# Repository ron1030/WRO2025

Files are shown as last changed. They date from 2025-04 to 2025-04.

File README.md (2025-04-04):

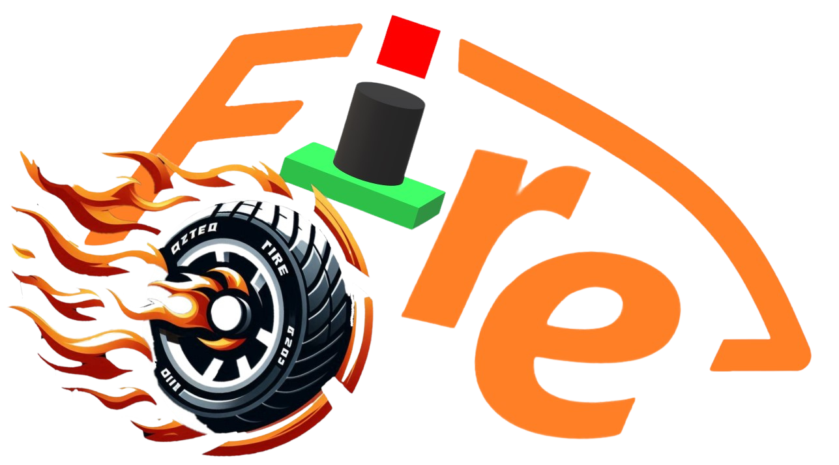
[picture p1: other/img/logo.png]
logo
 

- This is the official GitHub repository for the WRO TAIWAN team "__Fire On All Cylinders.__" All code, documentation, and files are located here.
- The design inspiration for both the hardware and software of this self-driving car came from last year’s model created by our sister team (Shinan-Fire-On-All-Cylinders) and drew upon the strengths of the world championship-winning model from last year. Based on this, we made improvements by upgrading the main controller from the "Raspberry Pi 4B" to the "Nvidia Jetson Nano" to enhance performance and introduce innovative design elements, making the vehicle more competitive.
- Here you can find the links to the technical report content and setup instructions, organized separately for learners and judges, for easy access during either learning or assessment. 
- In this technical document, the directory will be established based on the scoring criteria, and the directory headings will be hyperlinked for easy access for judges or learners to navigate to the key content of the technical document, facilitating quick assessment.
- **Special Reminder:** Due to internet speed factors, images may not display properly. If this occurs, please try refreshing the webpage to resolve the issue.
    #### [For Learners](learners_contents.md)
## Rubric for Judging Engineering Documentation 
- ###  ${{\color{red} Hardware Overview }} $ 
  #### 1. Mobility Management
    * [1-1 Vehicle 2D/3D Models in CAD ](models/Vehicle_2D_3D/README.md)
    * [1-2 Vehicle Chassis Design ](schemes/Vehicle_Chassis_Design/README.md)
    * [1-3 Motor Selection ](schemes/Motor/README.md)

  #### 2. Power and Sense Management
    - __2-1 Vehicle Design__
      - [2-1-1 BOM Parts List ](schemes/Parts_List/README.md)
      - [2-1-2 Circuit Design ](models/Circuit_Design/README.md)
      - [2-1-3 Hardware Fool-Proof Design ](schemes/Fool-Proof-Design/README.md) 
      - [2-1-4 Assembly Instructions & Wiring Diagrams ](schemes/Assembly_Instructions/README.md)    
      
    - __2-2 Power Management__
      - [2-2-1 Battery choice for self-driving cars ](schemes/Battery/README.md)  
      - [2-2-2 Power Supply System ](schemes/Power_Supply_System/README.md) 
   
    - __2-3 Controller Selection__
      - [2-3-1 Main Controller Comparison ](schemes/Main_Controller_Choosing/README.md)
      - [2-3-2 Motor & Sensor Intermediate I/O Controller Comparison ](schemes/Motor_Sensor_Controller_Choosing/README.md)
    - __2-4 Sense Management__
      - [2-4-1 Ultrasonic rangefinder ](schemes/HC-SR04/README.md)
      - [2-4-2 Gyroscope orientation sensor ](schemes/BNO055/README.md)
      - [2-4-3 Camera Selection ](schemes/Camera/README.md)
  
- ### ${{\color{red} Software Overview }} $ 
  #### 3. Obstacle Management
    - [3-1 Software Platform Construction ](src/System_Platform_Software/README.md)
    - [3-2 OpenCV Introduction ](src/OpenCV/README.md)
    - __3-3 Image Recognition Processing and Steering__
      - [3-3-1 Image Recognition Processing ](src/Image_Recognition_Processing/README.md)  
      - [3-3-2 Steering Control ](src/Steering_Control/README.md) 
      - [3-3-3 Automatically record the HSV values of the field ](src/Automatically_record_HSV/README.md)
    - __3-4 Programming__
      - [3-4-1 Open Challenge Code Overview ](src/Programming/Open_Challenge/README.md)
      - [3-4-2 Obstacle Challenge Code Overview ](src/Programming/Obstacle_Challenge/README.md)
      - [3-4-3 Distinctive Pseudo Code ](src/Distinctive_Pseudo_Code/README.md)
      - [3-4-4 Parking Instruction ](src/parking/README.md)
    - __3-5 Remote Connection__
      - [3-5-1 NoMachine Introduction ](other/NoMachine/README.md)
- ### ${{\color{red} Other}} $
  #### 4. Pictures – Team and Vehicle
    - [4-1 Team Members Introduction ](t-photos/README.md)
    - [4-2 Vehicle Photos ](v-photos/README.md)  
  #### 5. Performance Videos
    - [5-1 Open Challenge ](video/Open_Challenge/video.md)
    - [5-2 Obstacle Challenge ](video/Obstacle_Challenge/video.md)
    - [5-3 Self-Driving Car Design Process Video](video/Design_Process_Video/video.md)
  #### 6. GitHub Utilization
    - [6-1 GitHub Edit(VScode Edit/GIT) ](src/GitHub_Edit/README.md)
    - [6-2 GitHub Web Editing Languages ](src/GitHub_Languages/README.md)  
  #### 7. Engineering Factor  
    - [7-1 Work Diary](other/work_diary/README.md)
- ### ${{\color{red} CompetitionSchedule}} $  
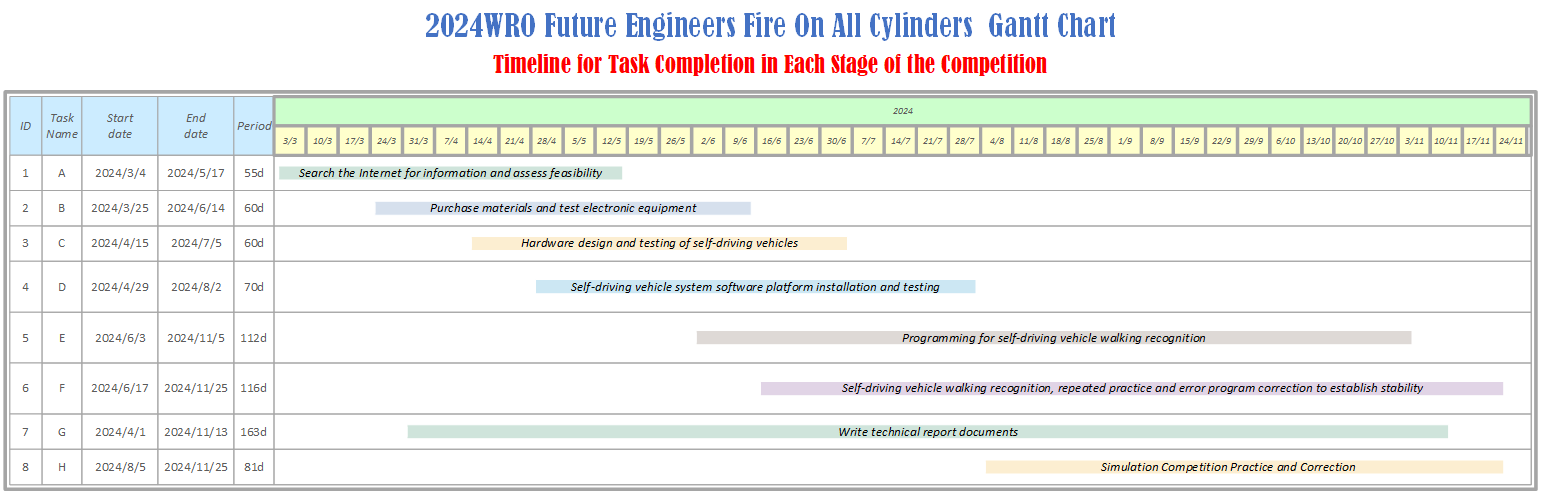
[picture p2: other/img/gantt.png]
Competition Schedule Gantt
#

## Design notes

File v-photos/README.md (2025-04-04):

<div align="center">logo</div>

## <div align="center"> Vehicle's photos</div>
- ### Vehicle's photos
<div align="center">
<table>
  <tr align="center">
    <th>Top View</th>
    <th>Bottom View </th>
  </tr>
    <tr align="center">
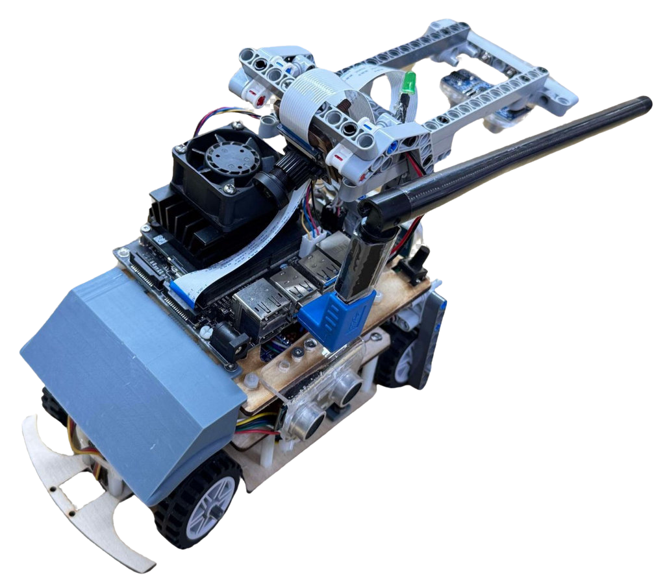
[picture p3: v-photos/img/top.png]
Top view
    <td> </td>
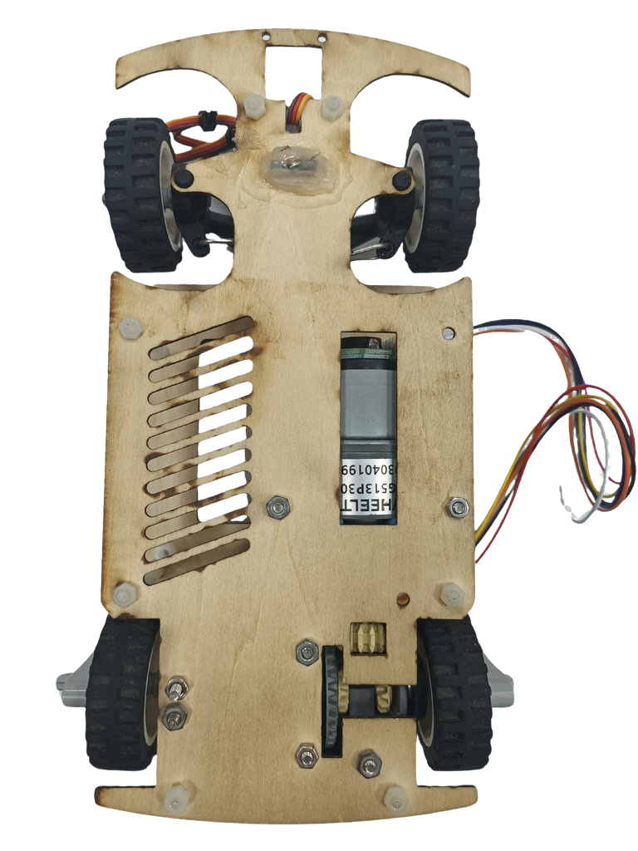
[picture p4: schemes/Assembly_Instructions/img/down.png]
Bottom view
    <td></td>

  </tr>
    <tr align="center">
    <th>Front view </th>
    <th>Rear view</th>
  </tr>
    </tr>
    <tr align="center">
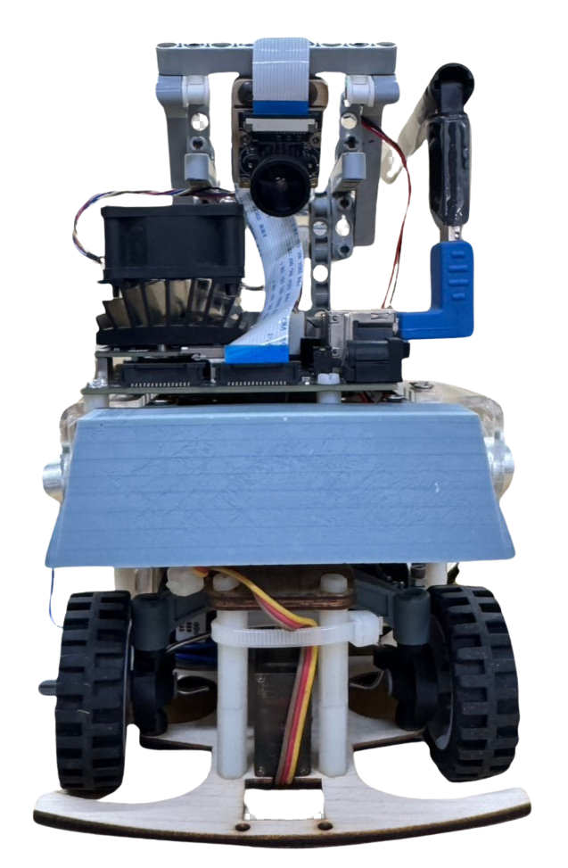
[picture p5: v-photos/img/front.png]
Front_view
    <td></td>
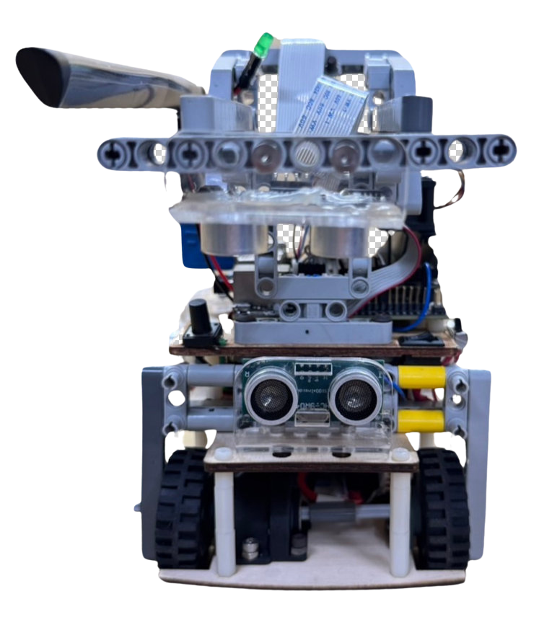
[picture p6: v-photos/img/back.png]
Rear_view
    <td></td>
  </tr>
  </tr>
    <tr align="center">
    <th>Left view </th>
    <th>Right view</th>
  </tr>
    </tr>
    <tr align="center">
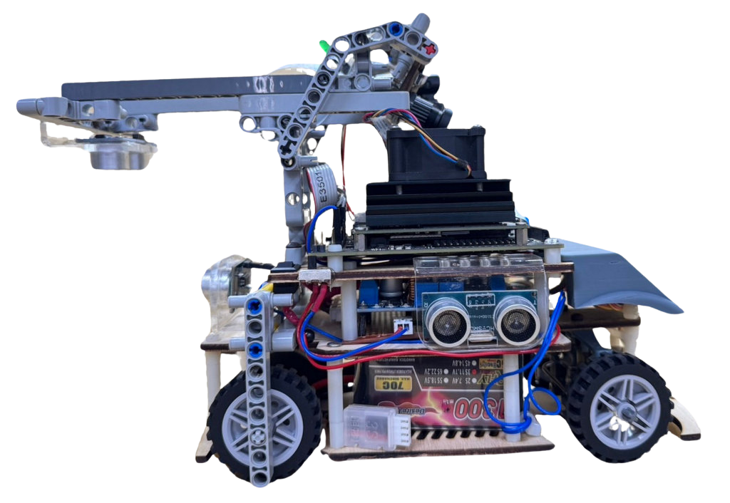
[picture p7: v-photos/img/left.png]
Left view
    <td></td>
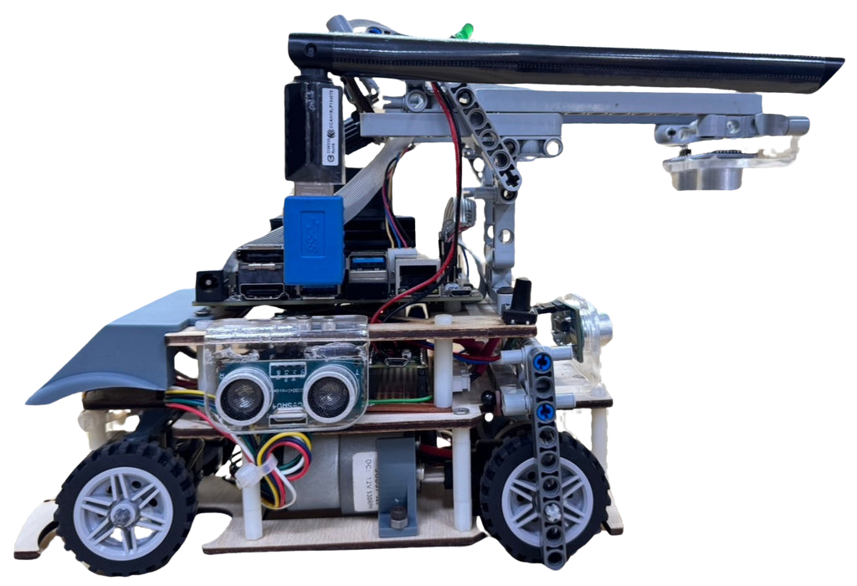
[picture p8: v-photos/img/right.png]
Right view
    <td></td>
  </tr>
</table>
</div> 

- ### Vehicle Body Structure Display Diagram
  <div align="center">
  <table>
    <tr>
    <th>Top View of the Overall Apparatus</th>
    <th>Middle Layer Structure Top View</th>
    <th>Top View of Vehicle Chassis</th>
    <th>Bottom View of Vehicle Chassis</th>
    </tr>
    <tr align="center">
      <td>  Top View of the Overall Apparatus
      </td>
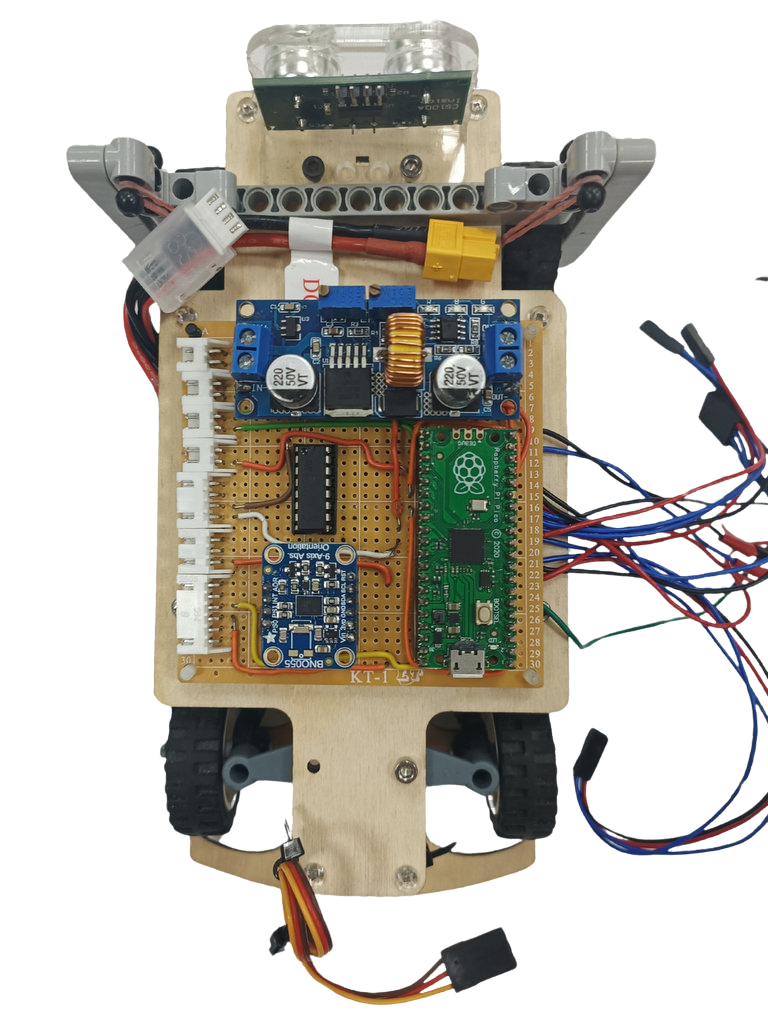
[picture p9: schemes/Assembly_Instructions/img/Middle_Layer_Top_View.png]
Middle Layer Structure Top View
      <td>
      </td>
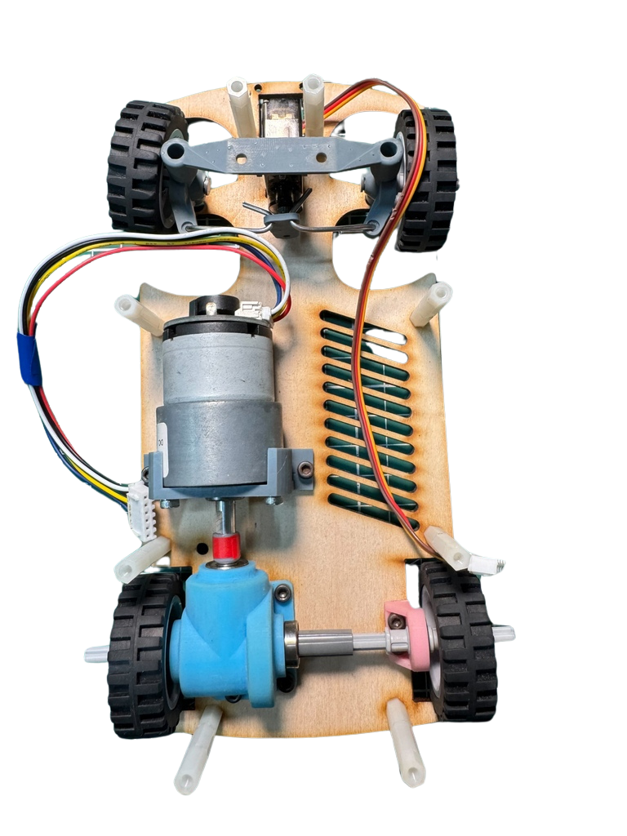
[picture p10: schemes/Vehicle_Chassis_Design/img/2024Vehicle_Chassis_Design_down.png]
Top View of Vehicle Chassis
      <td>
      </td>
      <td>Bottom View of Vehicle Chassis</td>
    </tr>
  </table>
  </div>
- ### Circuit Board
    <div align="center">
    <table>
      <tr align="center">
          <th> Circuit Board Top View</th><th>Circuit Board Button View</th>
      </tr>
      <tr align="center">
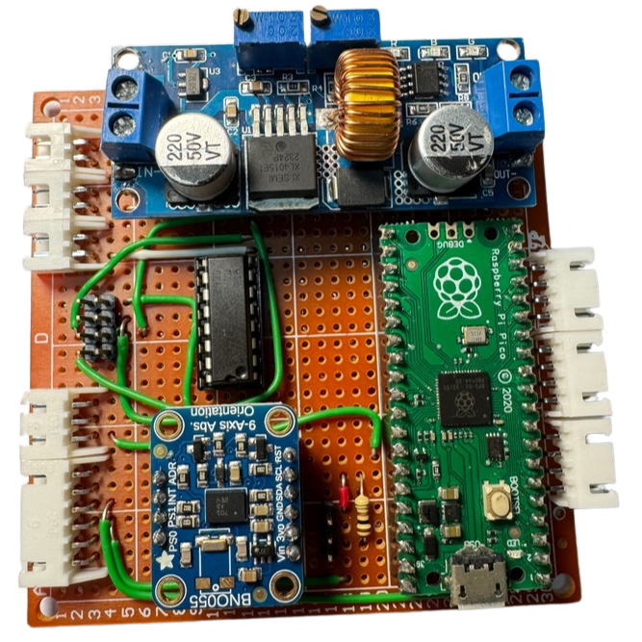
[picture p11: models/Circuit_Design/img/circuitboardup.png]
circuit_up
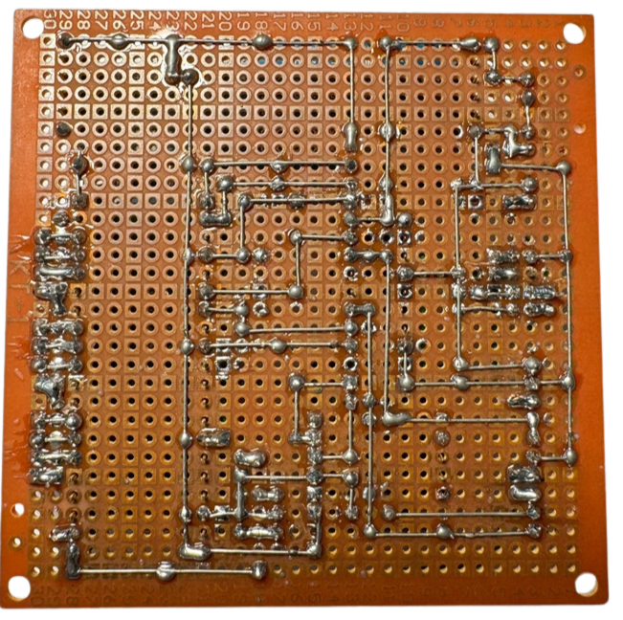
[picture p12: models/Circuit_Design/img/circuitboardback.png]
        <td>  </td><td></td>
      </tr>
    </table>
    </div>

# <div align="center">HOME[Return Home](../)</div>

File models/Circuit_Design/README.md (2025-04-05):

<div align="center">logo</div>

 ## <div align="center"> Circuit Design </div>
  __中文__
  - 在我們自動駕駛車輛的電路板設計中，我們採用EasyEDA這款電路設計軟體，它提供了直觀的圖形化介面。這項工具能顯著提升焊接過程中的佈線準確度，減少錯誤發生，並有效降低元件燒毀的風險。
  - 在實驗過程中，我們經常需要修改電路設計。為了便於快速調整與修改，我們採用通用型酚醛電路板，依照電路原理圖進行電子元件的焊接作業。這種實驗方法能為電路優化提供更高的設計彈性與操作便利性。
  - 電路板的主要功能在於為各類感測器、馬達及控制器提供電力與訊號連接，確保這些元件之間能夠實現無縫通訊與協同運作。

  __英文__
  - For our autonomous vehicle's circuit board design, we employ EasyEDA, a circuit design software that provides an intuitive graphical interface. This aids significantly in the soldering process by enhancing wiring accuracy, reducing errors, and effectively mitigating the risk of component burnout.
  - During our experiments, we frequently needed to modify the circuit. To facilitate adjustments and revisions, we used a general-purpose phenolic board to solder electronic components according to the circuit diagram. This approach offers greater flexibility and convenience in circuit improvements.
  - The primary function of a circuit board is to provide power and signal connections for various sensors, motors, and controllers, ensuring seamless communication and cooperation among them.

 - ### Circuit Board
<div align="center">
<table>
  <tr align="center">
      <th> Circuit Board Top View</th><th>Circuit Board Button View</th>
  </tr>
  <tr align="center">
     <td> circuit_up </td><td></td>
  </tr>
</table>
</div>

- ### Circuit Schematic Drawing
<div align="center">
<table>
  <tr align="center">
      <th>電路圖/Circuit Diagram</th><th>PCB佈局圖/PCB Layouts</th><th>原理圖/Circuit Schematic</th>
  </tr>
  <tr align="center">
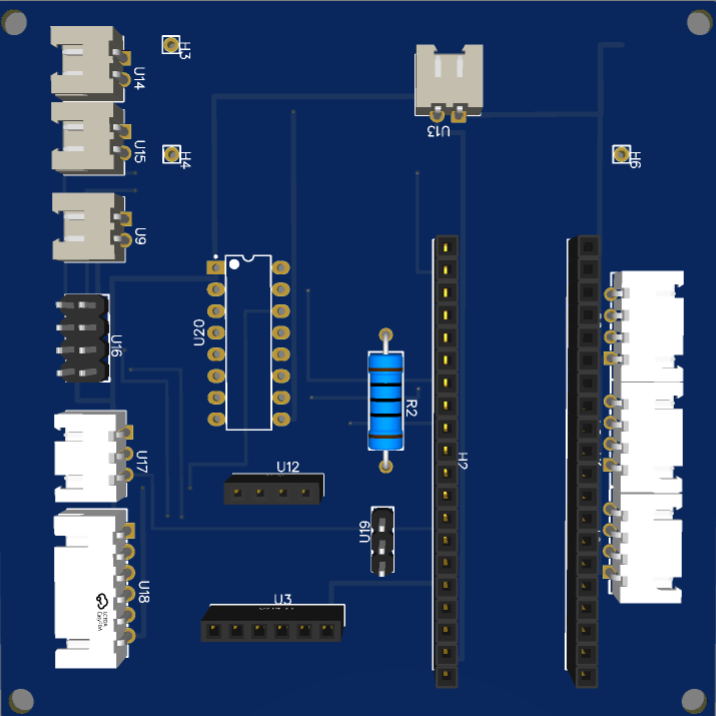
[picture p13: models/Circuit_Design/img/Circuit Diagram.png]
Circuit Diagram
     <td></td>
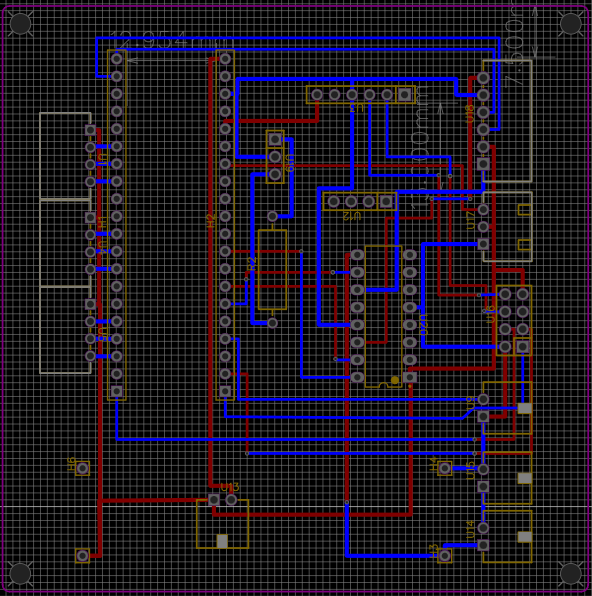
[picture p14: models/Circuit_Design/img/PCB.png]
PCB Layouts
     <td></td>
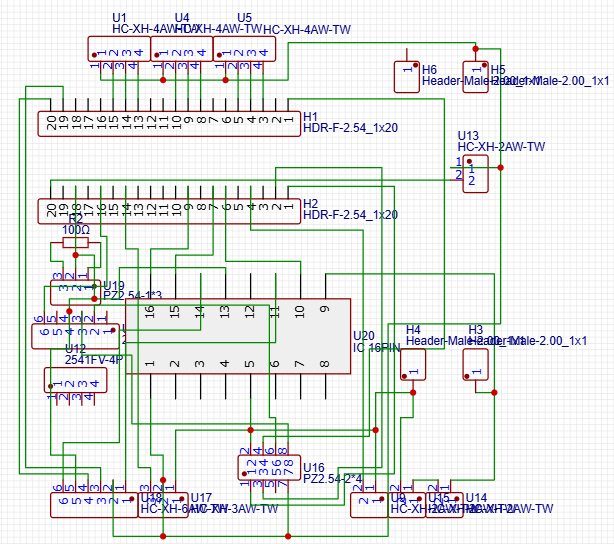
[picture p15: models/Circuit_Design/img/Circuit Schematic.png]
Circuit Schematic
     <td></td>
  </tr>
</table>
</div>

 ***
- ### Supplementary Information
 
 - #### EasyEDA Introduction
    - __EasyEDA__ 是一款免費的線上電子設計自動化 (EDA) 軟體，用於設計、類比電子電路和建立印刷電路板 (PCB)。它提供了簡單且用戶友好的圖形介面，並具有多種功能，使其成為業餘愛好者和專業工程師的理想選擇。
    - EasyEDA 可直接在網頁瀏覽器中使用，無需安裝軟體，可跨平台存取。它支援電路設計、模擬、PCB創建，還允許團隊合作進行電子專案。

    __EasyEDA__ is a free online Electronic Design Automation (EDA) software used for designing, simulating electronic circuits, and creating printed circuit boards (PCBs). It offers a simple and user-friendly graphical interface, with a variety of features that make it ideal for both hobbyists and professional engineers.
    - EasyEDA can be used directly in a web browser without the need for software installation, making it cross-platform accessible. It supports circuit design, simulation, PCB creation, and also allows teams to collaborate on electronic projects.

    __The main features of EasyEDA include:__

    __中文__ 
    - 原理圖設計：使用其廣泛的元件庫設計電路圖，其中包括電阻器、電容器、電晶體、積體電路 (IC) 等。原理圖設計：使用其廣泛的元件庫設計電路圖，其中包括電阻器、電容器、電晶體、積體電路 (IC) 等。
    - PCB 設計：支援多層 PCB 設計並提供自動佈線功能，幫助使用者有效率地佈局電路板。
    - 類比：內建的 SPICE 模擬允許使用者在製造之前虛擬測試電路。
    - 元件庫：提供龐大的元件庫，並支援從其他 CAD 工具匯入零件或建立自訂元件。
    - 協作工具：允許使用者與隊友分享設計以進行協同工作。
    - 雲端儲存：設計文件可以保存在雲端，方便從任何地方修改和訪問，並方便與團隊成員的協作。
    - 製造集成：EasyEDA 與 JLCPCB 無縫集成，允許用戶直接提交設計進行生產並輕鬆訂購客製化 PCB。

    __英文__
    - Schematic Design: Design circuit diagrams using its extensive component library, which includes resistors, capacitors, transistors, integrated circuits (ICs), and more.Schematic Design: Design circuit diagrams using its extensive component library, which includes resistors, capacitors, transistors, integrated circuits (ICs), and more.
    - PCB Design: Supports multi-layer PCB design and provides an auto-routing feature to help users efficiently layout their boards.
    - Simulation: Built-in SPICE simulation allows users to virtually test circuits before manufacturing.
    - Component Library: Offers a vast component library and supports importing parts from other CAD tools or creating custom components.
    - Collaboration Tools: Allows users to share designs with teammates for collaborative work.
    - Cloud Storage: Design files can be saved in the cloud, making it easy to modify and access from anywhere, as well as facilitating collaboration with team members.
    - Manufacturing Integration: EasyEDA is seamlessly integrated with JLCPCB, allowing users to directly submit designs for production and easily order custom PCBs.
     
    __總體而言，EasyEDA 是一款功能強大且易於使用的電子設計工具。無論您是初學者還是專業工程師，它都能提供滿足需求的功能。其基於雲端的存取便利性、簡潔的操作流程，以及與製造商的無縫整合，使其成為設計與生產電子電路的絕佳選擇。__

    __Overall, EasyEDA is a powerful and easy-to-use tool for electronic design. Whether you're a beginner or a professional engineer, it offers features to meet your needs. Its cloud-based accessibility, simple operation, and integration with manufacturers make it an excellent choice for designing and producing electronic circuits.__

    - Software link：[EasyEDA](https://easyeda.com/)
 <div align=center>
    <table>
    <tr>
    <th>EasyEDA 官方網站/EasyEDA of Official website.</th>
    <th>方案設計/Schematic Design</th>
    </tr><tr>
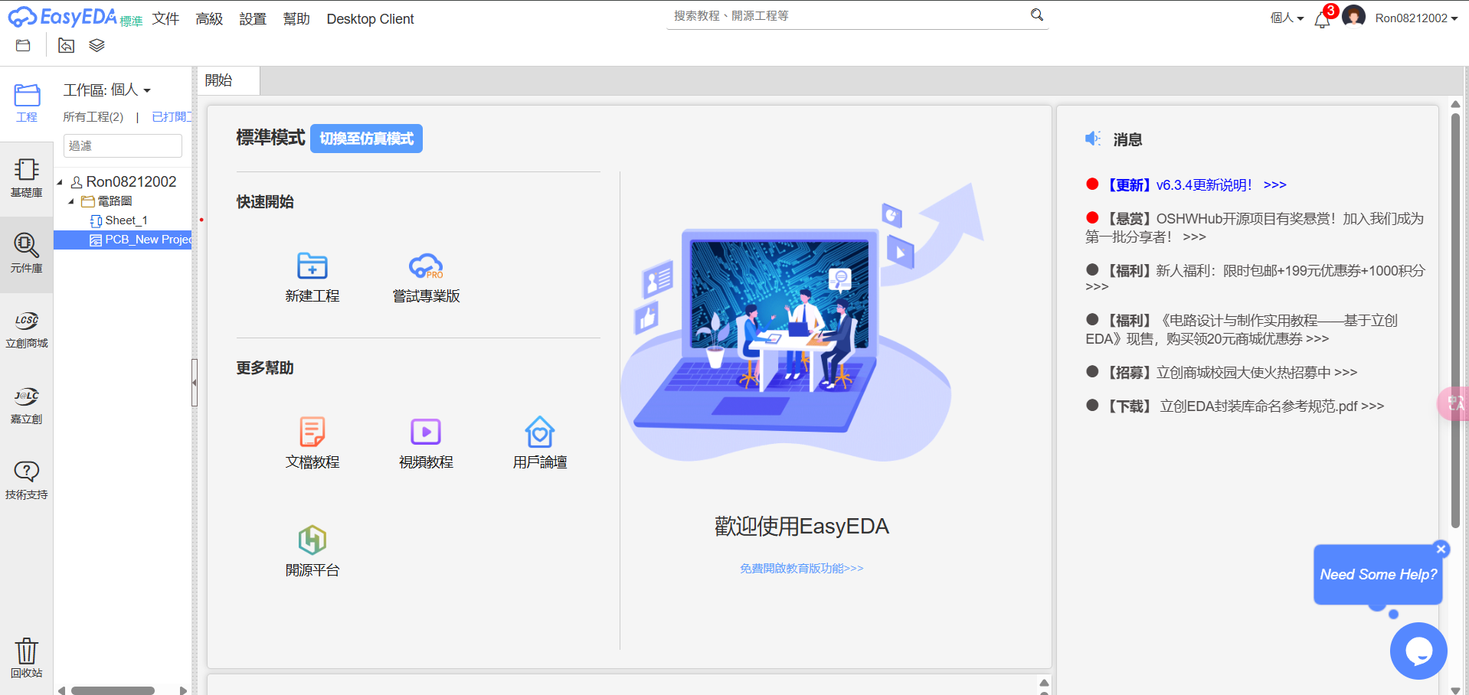
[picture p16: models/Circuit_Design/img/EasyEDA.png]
EasyEDA of Official website.
    <td></td>
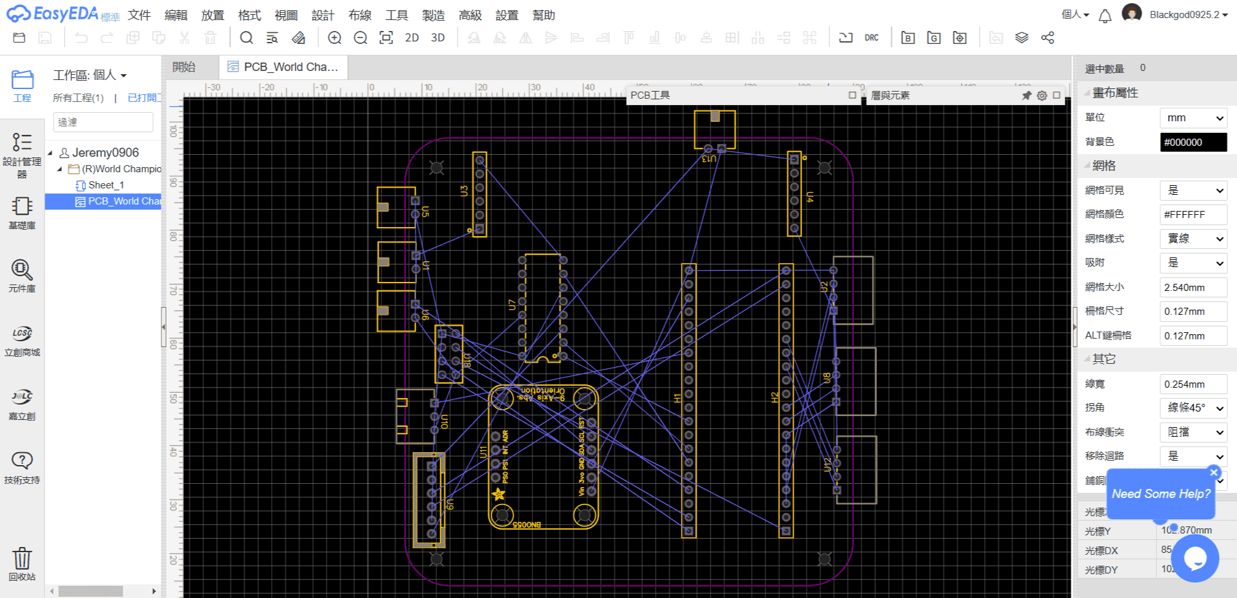
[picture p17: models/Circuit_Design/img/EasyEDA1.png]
Schematic Design
    <td></td>
    </tr>
    </table>
    </div>

# <div align="center">HOME[Return Home](../../)</div>

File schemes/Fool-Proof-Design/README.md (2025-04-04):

<div align="center">logo</div>

## <div align="center">Hardware Fool-Proof Design</div>

In the actual hardware design process, we frequently encountered issues where the Jetson Nano controller or IC would get damaged due to incorrect power connections or data line misplacements. To prevent these occurrences, we implemented male and female connectors for power supply and data transmission and used soldering to secure the circuit on a bakelite board, ensuring correct wiring. This improvement effectively reduced the risk of burnout for the Jetson Nano controller or IC, enhancing system stability and increasing product reliability and lifespan.
<div align=center>
<table>
<tr>
<th>2.5mm Connector 2/3 Pin Male/female Adapter Right Angle Pin Header White Socket</th>
<th>Circuit real-life photo</th>
</tr><tr>
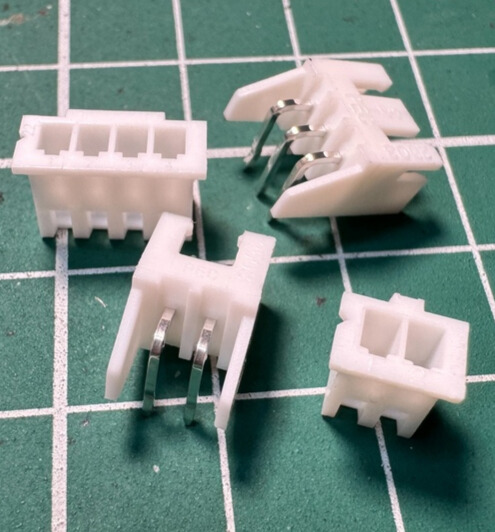
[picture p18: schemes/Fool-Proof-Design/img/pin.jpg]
pin
<td></td> 
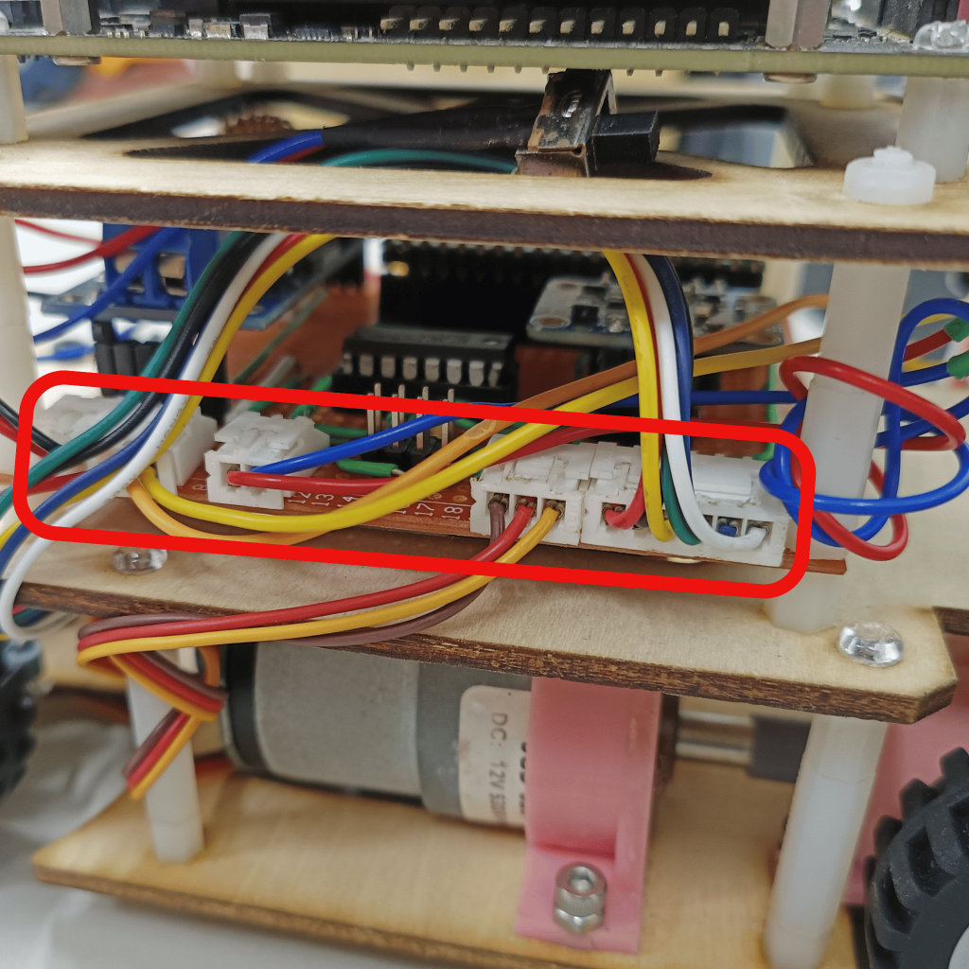
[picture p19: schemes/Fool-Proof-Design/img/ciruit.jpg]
ciruit
<td></td> 
</tr>
</table>
</div> 

# <div align="center">HOME[Return Home](../../)</div>

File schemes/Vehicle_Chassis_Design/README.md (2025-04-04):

<div align="center">logo</div>

## <div align="center">Vehicle Chassis Design Process</div> 

- ### Vehicle Chassis Design
  - The design inspiration for both the hardware and software of this self-driving car came from last year’s model created by our sister team (Shinan-Fire-On-All-Cylinders) and drew upon the strengths of the world championship-winning model from last year. Based on this, we made improvements by upgrading the main controller from the "Raspberry Pi 4B" to the "Nvidia Jetson Nano" to enhance performance and introduce innovative design elements, making the vehicle more competitive.
  - The vehicle chassis used in this competition is self-designed and developed.
  - We applied Ackermann steering geometry to the vehicle chassis and made improvements based on the shortcomings of last year’s mechanism, resulting in smoother obstacle avoidance and U-turns.
  - The following table shows the 3D models and finished products of the vehicle chassis.

    |3D Vehicle Chassis Design| Vehicle Chassis Top View | Vehicle Chassis Bottom View|
    |:----:|:----:|:----:|
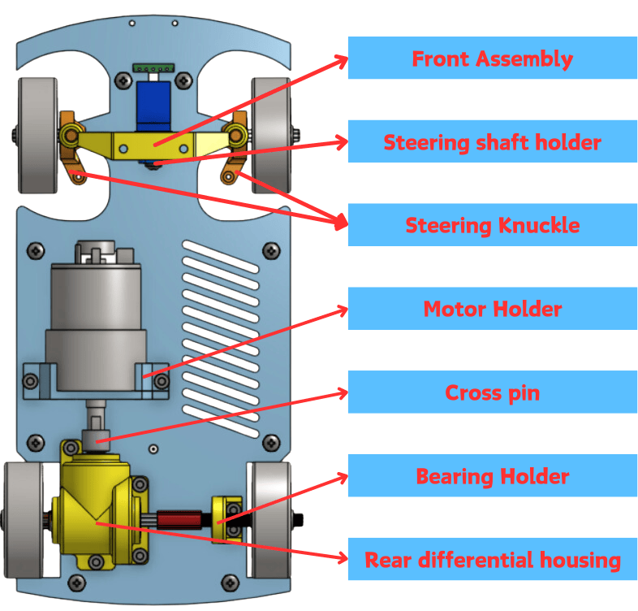
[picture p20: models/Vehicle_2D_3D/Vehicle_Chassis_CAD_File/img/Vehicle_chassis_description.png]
vehicle_chassis_design_3D
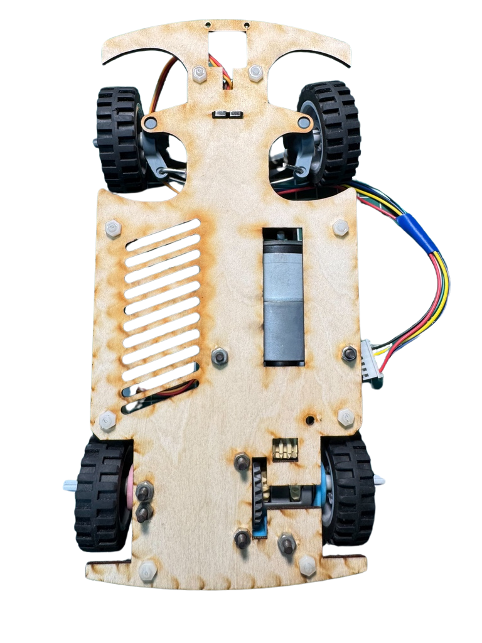
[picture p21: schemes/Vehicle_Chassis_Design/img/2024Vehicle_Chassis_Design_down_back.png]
down_view
    ||2024Vehicle_Chassis_Design_down||

  - We can customize the size and shape of parts according to the specific needs of the vehicle and use Stereolithography (SLA) 3D printers and laser cutters to design and manufacture all parts of the vehicle chassis, except for the gears, Lego 62821Gear Differential and tires.
  - To reduce rotational friction of the shafts, we integrated bearings into the vehicle's support frame, thereby increasing the vehicle's speed.
  - To precisely control the vehicle's optimal turning radius and flexibly adjust the Ackermann ratio, we used Stereolithography (SLA) 3D printers and 3D modeling technology to design the support frame for the Ackermann steering geometry on the vehicle chassis based on specific requirements.

- #### Vehicle Chassis Improvement Record

  - The following is a comparison between last year’s model (Shinan-Fire-On-All-Cylinders) and this year’s improved model, recorded in the table below:
  ### __2023 Competition Prototype__

  <div align=center>
  <table>
  <tr align=center>
  <th>2023 Competition Prototype </th>
  <th>2023 Competition Prototype</th>
  <th>Explanation</th>
  </tr><tr >
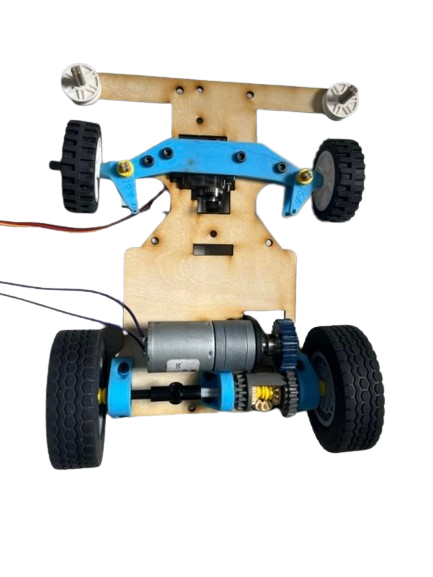
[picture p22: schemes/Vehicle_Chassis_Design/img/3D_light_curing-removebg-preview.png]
2023car_wood_up-removebg-preview
  <td width="30%"></td>
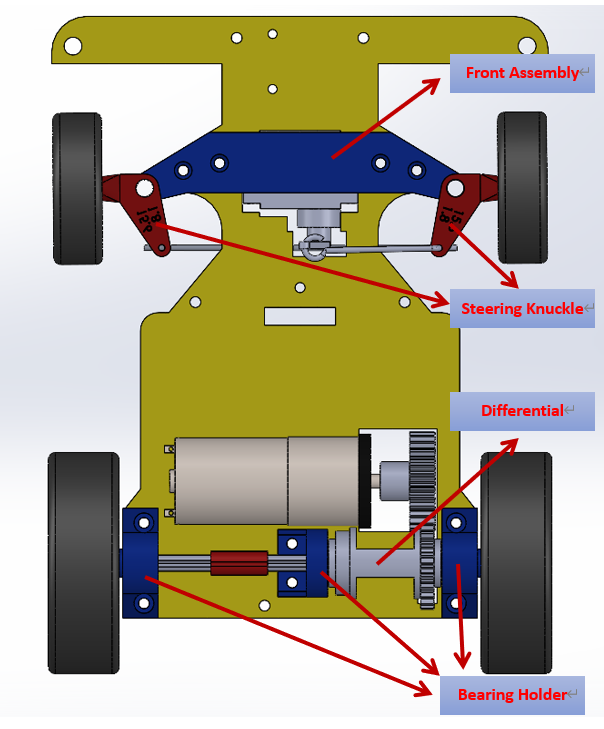
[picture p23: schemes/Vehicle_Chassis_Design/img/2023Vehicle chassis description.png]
2023Vehicle chassis description
  <td width="30%"></td>
  <td>Last year's vehicle chassis had several issues:<br><br>
    <ol>
      <li>The position of the front steering servo motor was too low, causing it to easily rub against the ground.</li>
      <li>The 3D-printed steering knuckle part was prone to breaking upon collision with walls.</li>
      <li>The gear differential was not compatible with the configuration of the front and rear DC motors, limiting the overall vehicle design.</li>
    </ol>  
      </td>
    
  </tr>
  </table>
  </div>
 
  ### __Final Build__

  <div align=center>
  <table>
  <tr align=center>
  <th>Photos of the final Build</th>
  <th>3D modeling of the final Build</th>
  <th>Explanation</th>
  </tr><tr>
  <td width="30%"></td>
  <td width="30%"></td>
  <td>In addition to addressing the issues of last year's competition model, we also reduced the vehicle's width to make it easier to maneuver through obstacles.</td>
  </tr>
  </table>
  </div>

- ###  Gear Differential
  For a vehicle's single drive system, a gear differential is an indispensable device because it effectively balances power and distributes it to different wheels, allowing each driven wheel to rotate at different speeds, especially during turns. This is crucial for improving the vehicle's agility and handling performance.

   - #### Modifications and evolution of the gear differential.
      In this competition, we used the LEGO gear differential 62821 combined with a homemade gear differential housing to achieve the vehicle's driving and steering functions.
  <div align=center>
  <table>
  <tr align=center>
  <th>LEGO 6573 Gear Differential</th>
  <th>LEGO 62821 Gear Differential</th>
  <th>Homemade Gear Differential housing</th>

  </tr><tr align=center>
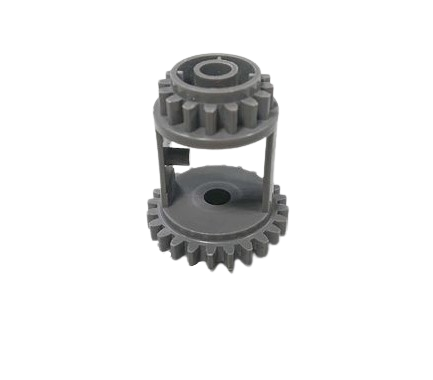
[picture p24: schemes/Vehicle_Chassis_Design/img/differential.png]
  <td width="30%"></td>
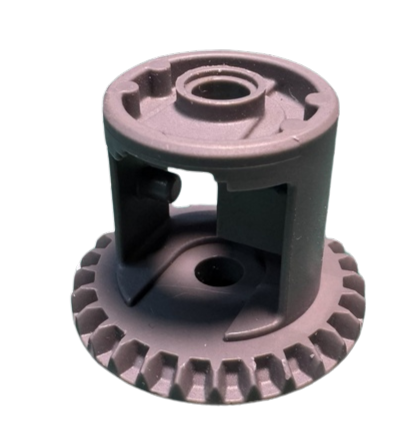
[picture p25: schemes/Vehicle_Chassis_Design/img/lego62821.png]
  <td width="30%"></td>
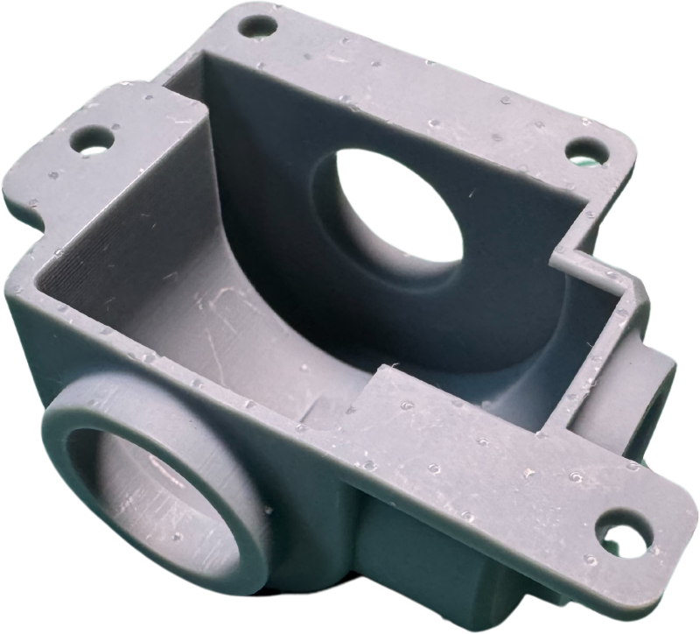
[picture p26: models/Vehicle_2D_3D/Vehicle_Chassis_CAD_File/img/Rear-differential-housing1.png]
  <td width="30%"></td>
  </tr>
  </table>
  </div>

    - #### Reason for Modification
       - Due to changes in the motor's dimensions this year, the LEGO 6573 gear differential used in last year's model can no longer be utilized. As a result, we need to design a custom differential to accommodate the new dimensions of the vehicle body and ensure the entire vehicle system operates smoothly.
       - By using a custom-made gear differential housing to accommodate gear meshing and fixation, the power transmission loss was reduced.
  <div align=center>
  <table>
  <tr align=center>
  <th>LEGO 6573 Gear Differential</th>
  <th colspa ="2">Homemade Gear Differential</th>
  </tr><tr align=center>
  <td width="50%"></td>
  <td width="50%"></td>
  </tr>
  </table>
  </div>

- ### Supplementary information
    - #### What is an Ackermann Steering Geometry?
      __Ackermann Steering Geometry Introduction__
        - The Ackermann steering geometry, proposed by German automotive engineer Lankensperger in 1817, is a steering system design used in automobiles. It was developed to address the geometric discrepancy in the paths of the inner and outer turning wheels when a vehicle makes a turn.
        - People apply Ackermann steering geometry to the steering mechanism of vehicles. Through the corresponding cranks of the four-linkage system, the steering angle of the wheels relative to the projected tire is increased by about 2 to 4 degrees. This results in the rough convergence of the trajectory centers of all four wheels along the extension line of the rear axle, thereby achieving the vehicle's turning.
      
      Ackermann_steering_geometry  

      Reference Link：[Ackermann steering geometry@Wikipedia](https://zh.wikipedia.org/zh-tw/%E9%98%BF%E5%85%8B%E6%9B%BC%E8%BD%89%E5%90%91%E5%B9%BE%E4%BD%95)
      #### The principle of Ackermann steering geometry is based on the following concepts:     
       - __Difference in Turning Radius:__ When the vehicle makes a turn, the two front wheels need to rotate at different angles to allow the vehicle to pivot around a central point.
       - __Turning Angles of the Two Front Wheels:__ The design of the Ackermann steering geometry ensures that both front wheels pass through a central point simultaneously during steering.
    - Compared to the Ackermann steering geometry made from the original 0% LEGO bricks, the steering mechanism of this competition vehicle is designed with reference to an 80% Ackermann steering geometry. It offers advantages such as reduced resistance and smoother turns. The Ackermann steering geometry parts are produced using a stereolithography (SLA) 3D printer. However, the most challenging aspect of the process was adjusting the Ackermann ratio to achieve the ideal turning angle for our vehicle to navigate around blocks effectively.  
  
  - #### Why Choose an 80% Ackermann Ratio?

    - In theory, this design is the optimal choice for smooth and efficient turns. However, it may lead to excessive tire wear. Therefore, in automobile design, a 100% Ackermann ratio is usually not chosen. Compared to a 100% Ackermann ratio, an 80% Ackermann ratio allows for smoother, more predictable turns, improves maneuverability, and reduces tire wear.
  
    - #### Calculating the Ackermann Angle Graphically (a-b = ack)
    <div align="center">
    <table>
    <tr align=center>
    <td>angle</td>
    <td>Ackermann_steering_geometry_lego</td>
    </tr>
    </table>
    </div>

    Reference Video website：[汽车转弯 没那么简单: 阿克曼转向几何是个啥？How does Ackerman steering geometry work?](https://www.youtube.com/watch?v=8AimxDPWKcM)

# <div align="center">HOME[Return Home](../../)</div>

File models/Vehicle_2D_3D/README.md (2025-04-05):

<div align="center">logo</div>

## <div align="center">3D Vehicle Model Design</div>
__中文__
- 這次比賽使用的車輛底盤是我們自主研發設計的。以下將介紹車輛底盤的設計與生產流程。
- 我們使用Onshape設計車輛的3D模型結構，並根據底盤的特點，使用雷射切割機和立體光刻（SLA）3D列印機等設備製造必要的車輛零件。

__英文__
- The vehicle chassis used in this competition is our in-house, self-developed design. The following will introduce the vehicle chassis design and production process.
- We use Onshape to design the 3D model structure of the vehicle, and based on the chassis's characteristics, we manufacture the necessary vehicle parts using equipment such as laser cutting machines and Stereolithography (SLA) 3D Printer.
<div align=center>
    <table>
    <tr>
    <th>2024 舊版/Old version </th>
    <th>2025 新版/New version</th>
    </tr><tr>
    <td>Vehicle_cad</td> 
    <td>vehicle Underfloor</td> 
    </tr>
    </table>
 </div> 

- ### Onshape Model Draft
  - #### 3D建模軟體--Onshape介紹
  - #### 3D modeling software -- Onshape Introduction
  __中文__
  - 我們使用 Onshape 設計自動駕駛汽車的 3D 模型。 Onshape 是一款免費且易於使用的基於網路的 CAD 軟體。
  - 在Onshape中建立模型後，可以輸出2D尺寸圖，然後可以將其發送到雷射切割機進行切割，或轉換後發送到3D列印機進行輸出。
  - 本次競賽創建的所有 3D/2D 車輛模型均在 OnShape 中設計。

  __英文__
  - We use Onshape to design 3D models of self-driving cars. Onshape is a free and easy-to-use web-based CAD software.
  - After creating a model in Onshape, you can output a 2D dimension drawing, which can then be sent to a laser-cutting machine for cutting or converted and sent to a 3D printer for output.
  - All 3D/2D vehicle models created for this competition were designed in OnShape.
  - Software Website：[Onshape](https://www.onshape.com/en/) 
    <div align=center>
    <table>
    <tr>
    <th>Onshape 網站/Onshape Website </th>
    <th>車輛底盤部件的 3D CAD 繪圖/3D CAD drawing of vehicle chassis components</th>

    </tr><tr>
    <td>Vehicle_cad</td> 
    <td>vehicle Underfloor</td> 

    </tr>
    </table>
    </div> 

  - #### Design and production of 3D/2D models for vehicle parts    
    <div align=center>
    <table>
    <tr>
    <th>3D Vehicle Model </th>
    <th>Vehicle Underfloor</th>
    <th>Vehicle Mid-Deck</th>
    <th>Vehicle Top Deck</th>
    </tr><tr>
    <td>Vehicle_cad</td> 
    <td>vehicle Underfloor</td> 
    <td>Vehicle_Mid_deck</td> 
    <td>Vehicle_Top_Deck</td>
    </tr>
    </table>
    </div> 
     <div align=center>
    <table>
    <tr>
    <th>3D Vehicle Chassis Design</th>
    <th>3D Vehicle Chassis Models</th>
    </tr><tr>
    <td></td> 
    <td></td> 
    </tr>
    </table>
    </div> 

  - #### The Production of Vehicle Chassis Panels Introduction - Using a laser-cutting machine
    - A laser-cutting machine is a device that utilizes a laser beam to cut materials. The laser beam has high energy density and can cut a variety of materials, including wood, metal, plastic, paper, and more, quickly and precisely.
    - We use the laser-Cutting machine provided by the school to produce the 'vehicle underfloor,' 'vehicle mid-deck,' and 'vehicle top deck' required for the vehicle chassis. We cut 3mm thick wooden boards according to the self-designed vehicle flat panel dimensions chart.  
    - We use lighter-weight wooden boards as the material for vehicle flat panels to reduce the vehicle's weight. 
    - With the upgrade of the main controller from the "Raspberry Pi 4B" to the "Nvidia Jetson Nano," the structure and dimensions of the vehicle chassis were also adjusted accordingly to better accommodate the needs of the new system.
    - When designing the vehicle structure, we first used 3D modeling software Onshape to create draft designs and generate engineering drawings (DXF files). These drawings were then imported into the laser cutter's editing software (LaserWorkV) for detailed adjustments. Finally, based on the design drafts, we outlined the lines and cut the wooden boards into shape.

  - #### Vehicle Chassis Panels Dimensions Chart 
    <div align=center>
    <table>
    <tr>
    <th>Vehicle Underfloor</th> 
    <th>Vehicle Mid-Deck</th>
    <th>Vehicle Top Deck</th>
    </tr><tr>
    <td>2D_bottom</td> 
    <td>2D_mid</td> 
    <td>2D_top</td>
    </tr>
    </table>
    </div> 

  - #### Vehicle Body Wooden Panels Produced Using a Laser Cutting Machine
     <div align=center>
     <table>
     <tr>
     <th>Vehicle Underfloor</th>
     <th>Vehicle Mid-Deck</th>
     <th>Vehicle Top Deck</th>
     </tr>
     <tr>
     <td>Vehicle Underfloor</td>
     <td>Vehicle Mid-Deck</td>
     <td>Vehicle Top Deck</td>
     </tr>
     </table>
     </div>
  - ####  Operation of Laser-Cutting Machine
    <div align="center">car_board</div>

 - ###  3D Vehicle Model - Onshape Model Sketch.
     We used Onshape for the design and employed a Stereolithography (SLA) 3D Printer to manufacture the 3D-printed parts for the vehicle chassis needed for this competition. The design and production process is as follows:
    - #### The usage and introduction of Stereolithography (SLA) 3D printers 
      - Stereolithography (SLA) 3D printing technology uses liquid photosensitive resin as the material and forms objects layer by layer through laser curing.  SLA printers excel in producing high-precision parts with complex geometries, making them especially suitable for prototyping and model making where fine details are required.
      - To address the limitations in printing range and quality of last year's SLA 3D printer, we specifically adopted an 8K resolution SLA 3D printer (Phrozen Sonic Mini 8K) and an ultraviolet curing box to enhance print quality and precision.

       - __The usage process of SLA 3D printers typically includes the following steps:__ 
         - __Design and Preparation:__ First, design the 3D model in CAD software and convert it into a printable STL file.
         - __Print Setup:__ Load the STL file into the slicing software of the SLA printer, and set printing parameters such as layer thickness and resin type.
         - __Printing Process:__ The SLA printer uses a laser to cure the resin layer by layer, forming the model. Since each layer is precisely cured by the laser, the printed product has high precision and a smooth surface.
         - __Post-Processing:__ After printing, the finished product is removed from the resin vat, cleaned to remove excess resin, and subjected to secondary curing in a UV curing box to increase hardness and stability.
      
          SLA 3D printers are widely used in industries such as manufacturing, healthcare, jewelry, and industrial design. Due to their high precision and fine surface treatment, they are particularly suitable for producing parts that require high quality and detailed features.

      - #### Comparison between Stacked 3D Printer and  Stereolithography (SLA) 3D Printer
         By conducting practical printing and operation comparisons of the 3D vehicle parts, we have reached the following conclusions:
        <div align="center">
        <table>
        <tr align="center">
        <th rowspan="2">Photo</th>
        <th> Stacked 3D Printe</th>
        <th> Stereolithography (SLA) 3D Printer(Phrozen Sonic Mini 8K)</th>
        </tr><tr align="center">
        <td>Stacked_3D_Printe</td>
        <td>Stereolithography_3D_Printer</td>
        </tr><tr align="">
        <td>The required printing time</td>
        <td>Faster</td>
        <td>Slower</td>
        </tr><tr>
        <td>Exterior</td>
        <td>Exterior with signs of layering</td>
        <td>Smooth</td>
        </tr><tr>
        <td>Hardness</td>
        <td>Dependent on the density</td>
        <td>Dependent on the exposure time</td>
        </tr>
        </tr><tr>
        <td>Size dimensions.</td>
        <td>Supports larger dimensions but does not support overly small dimensions.</td>
        <td>Supports smaller dimensions.</td>
        </tr>
        </table>
        </div>
     - #### Description of the resin used in "Stereolithography (SLA) 3D Printer."
       The types of resin used in Stereolithography (SLA) 3D printers vary, and different resins offer distinct performance comparisons. Common types of SLA resins include:
        - __Standard resin:__ Suitable for general use, offering good surface finish, but relatively lower strength and durability.
        - __High-strength resin:__ Provides higher tensile strength and rigidity, ideal for parts that need to withstand force.
        - __Flexible resin:__ Has elasticity and flexibility, suitable for parts that require some degree of deformation.
        - __High-temperature resin:__ Excellent heat resistance, suitable for parts that need to operate at high temperatures.
        - __Impact-resistant resin:__ Offers good impact resistance and toughness, ideal for parts that are prone to collisions.

          Each type of resin has different advantages in terms of physical properties, surface quality, strength, and durability, and the choice of resin depends on the specific application requirements.

        During the competition, the vehicle often collided with side walls and obstacles, causing parts like the "Steering shaft holder" and "Cross pin" to break. As a result, we conducted experimental tests with impact-resistant resin and high-strength resin. The tests showed that parts made from impact-resistant resin were too soft to meet the requirements. In the end, we chose to use high-strength resin to manufacture these parts, improving their durability and strength.

    <div align=center>
    <table>
    <tr>
    <th>High-strength resin</th>
    <th>Impact-resistant resin</th>
    <th>Printing completed<th>
    </tr><tr>
    <td></td> 
    <td></td> 
    <td>3D Finished Product.<td>
    </tr>
    </table>
    </div> 

    - ####  3D Vehicle Model Dimension Diagram
      <div align=center>
      <table>
      <tr>
      <th>Front Assembly</th>
      <th>Steering Knuckle</th>
      <th>Bearing Holder</th>
      <th>Rear differential housing</th>

    </tr><tr>
      <td>Front Assembly</td> 
      <td>Steering Knuckle</td> 
      <td>Bearing Holder</td>
      <td>Rear differential housing</td>
      </tr>
      </table>
      </div> 
       <div align=center>
      <table>
      <tr>
      <th>Steering shaft holder</th>
      <th>Cross pin</th>
      <th>Motor Holder</th>

    </tr><tr>
      <td>Steering shaft holder</td>
      <td>Cross pin</td>
      <td>Motor Holder</td>
      </tr>
      </table>
      </div> 

  - ####  Vehicle body support components produced with Stereolithography (SLA) 3D Printer
      <div align=center>
      <table>
      <tr>
      <th>Front Assembly</th>
      <th>Steering Knuckle</th>
      <th>Steering shaft holder</th>
      <th>Cross pin</th>
      </tr><tr>
      <td>Front Assembly</td> 
      <td>Steering Knuckle</td> 
      <td>Steering-shaft-holder</td> 
      <td>Cross-pin</td>
      </tr>
      </table>
      </div> 
      <div align=center>
      <table>
      <tr>
      <th>Bearing Holder</th>
      <th colspan="2"> Rear differential housing</th>
      <th>Motor Holder</th>
      </tr><tr>
      <td>Bearing-Holder</td> 
      <td>Rear-differential-housing</td>
      <td>Rear-differential-housing</td>
      <td>Motor Holder</td>
      </tr>
      </table>
      </div> 

 ***
- ### Supplementary Information
    - __Maintenance Process:__

       Without regular maintenance, a stereolithography 3D printer may become clogged with resin and become unusable, requiring periodic cleaning. So we recorded the cleaning methods we learned from our seniors and started cleaning ourselves.
     
    1. After printing is completed, the object will adhere to the printing platform, so we remove the platform for cleaning.
    2. Place the platform on a rack and put it into the UV curing washing machine.    
    3. Set the time and wait for the washing machine to complete the cleaning. The machine will rotate the alcohol in the washing tank to perform the first cleaning of the platform and the object.
    4. Rinse the alcohol off the finished product with water.
    5. Use a scraper to remove the object from the platform.
    6. Remove the support structures from the edges of the object.
    7. Perform a second cleaning with alcohol to thoroughly clean the resin off the object.
    8. Clean any remaining resin off the platform with alcohol.
    9. Finally, dry the platform and reinstall it back onto the stereolithography 3D printer of machine.

    <div align="center">
    <table>
    <tr>
    <td>Step 1</td>
    <td>Step 2</td> 
    <td>Step 3</td></tr>
    <tr align="center">
    <td></td>
    <td></td> 
    <td></td>
    </tr>
    <td>Step 4</td>
    <td>Step 5</td> 
    <td>Step 6</td></tr>
    <tr align="center">
    <td></td>
    <td></td>
    <td></td>
    </tr>
    <td>Step 7</td>
    <td>Step 8</td>
    <td>Step 9</td></tr>
    <tr>
    <td></td>
    <td></td>
    <td></td>
    </tr>
    </table>
    </div>

   - Since the parts printed by the stereolithography (SLA) 3D printer are relatively soft, we need to place them in an ultraviolet curing box, where they are exposed to UV light for secondary curing. This process hardens the parts and reduces deformation, thereby preventing any negative impact on the vehicle's movement.

   <div align=center>
    <table>
    <tr>
    <th>Ultraviolet curing box</th>
    </tr><tr>
    <td>light_again</td>
    </tr>
    </table>
    </div>

# <div align="center">HOME[Return Home](../../)</div>

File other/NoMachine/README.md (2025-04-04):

<div align="center">logo</div>

## <div align="center">NoMachine Introduction</div> 

- NoMachine is a high-performance remote desktop access software that offers cross-platform support, allowing users to remotely connect to another computer anytime, anywhere. Its main features include a fast and smooth remote operation experience, compatible with various operating systems such as Windows, macOS, Linux, iOS, and Android.
- NoMachine uses advanced image compression technology to ensure high-quality graphics and audio transmission, even in low-bandwidth network environments. Additionally, NoMachine supports remote printing, file sharing, USB transfer, and other functions, making it ideal for remote work, technical support, and multi-device management. 
- Especially for development platforms like the NVIDIA® Jetson Nano, NoMachine provides a convenient solution for wireless remote control, greatly enhancing device operational flexibility and application possibilities.

- ### Installing NoMachine
    - #### On the NVIDIA® Jetson Nano
      To install NoMachine on an NVIDIA® Jetson Nano, follow these steps:

      __Download NoMachine for Linux ARM:__
        - In the Jetson Nano’s controller interface, open a browser and navigate to the <a href="https://downloads.nomachine.com/download/?id=1" target="_blank">NoMachine download page</a>. Locate and select the NoMachine for Linux ARM (64-bit) software package, which is compatible with the Jetson Nano.      
        - After downloading, open the terminal and enter cd Downloads to navigate to the folder.
        ```
        cd Downloads
        ```
        - Then, enter unzip Nomachine_7.10.1_1_arm64.zip to unzip the file.
        ```
        unzip Nomachine_7.10.1_1_arm64.zip
        ```
        - Once extracted, enter sudo dpkg -i nomachine_7.10.1_1_arm64.deb to install.
        ```
        sudo dpkg -i nomachine_7.10.1_1_arm64.deb
        ```
        If you see this icon, the installation is complete.
        
        <td>nomachine download</td>

    - #### On the Windows System  of Computer        
      To install NoMachine on Windows, follow these steps:
      
      __Download NoMachine for Windows (64-bit)__
        - In a Windows computer, open a browser and go to the <a href="https://downloads.nomachine.com/windows/?id=3" target="_blank">NoMachine download page</a>. Find and select the NoMachine for Windows (64-bit) software package to download the version compatible with Windows.
        - After downloading, run the installation file. You will need to __restart__ the computer afterward.
        <td>nomachine download</td>

    - #### Connecting to Jetson Nano
         Open NoMachine on Windows.

         nomachine open

        Enter the Jetson Nano IP address.

        Find the IP address.
        ```
        ifconfig  
        ```
        Find the username.
        ```
        hostname 
        ```
        <td>nomachine ip</td>

        After connecting, enter the username and password. 
        <td>nomachine connet</td>

        Once done, you’ll be able to connect.
        <td>nomachine jetson ok</td>

    - #### Reference link:
    - <a href="https://www.waveshare.net/wiki/JetRacer_ROS_AI_Kit_%E6%95%99%E7%A8%8B%E4%BA%8C%E3%80%81%E5%AE%89%E8%A3%85Jetson_nano_%E9%95%9C%E5%83%8F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" target="_blank">Waveshare Wiki</a>
    - <a href="https://www.nomachine.com/" target="_blank">NoMachine Website</a>
    - <a href="https://en.wikipedia.org/wiki/NX_technology" target="_blank">Wikipedia</a>

# <div align="center">HOME[Return Home](../../)</div>

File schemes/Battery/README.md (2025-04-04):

<div align="center">logo</div>

## <div align="center">Battery choice for self-driving cars</div> 
 At last year's international competition, our coach observed that most teams were using 18650 batteries to power their vehicles. He tasked us with comparing the differences between 3S Lithium Polymer (LiPo) and 18650 batteries to determine the optimal battery type for our competition vehicle this year.
### Comparison between 3S Li-Polymer and 18650 Li-ion batteries
  - The following is a comparison of the advantages and disadvantages of 3S Li-Polymer batteries and 18650 Li-ion batteries with the same voltage configuration.
  <table border="1">
    <thead>
      <tr>
      <th>Item</th>
      <th>3S Li-Polymer Battery</th>
      <th>18650 Battery</th>
      </tr>
    </thead>
    <tbody>
      <tr>
      <th>photo</th>
      <td>lipo_battery</td>
      <td></td>
      </tr>
      <tr>
      <th>Voltage Range</th>
      <td>11.1V (nominal), up to 12.6V (fully charged)</td>
      <td>11.1V (nominal), up to 12.6V (fully charged)</td>
      </tr>
      <tr>
      <th>Energy Density</th>
      <td>Higher energy density compared to the same weight</td>
      <td>Higher capacity per unit volume compared to LiPo</td>
      </tr>
      <tr>
      <th>Weight</th>
      <td>Lighter, good for reducing load</td>
      <td>Relatively heavier</td>
      </tr>
      <tr>
      <th>Output Current</th>
      <td>Supports high discharge rates (C-Rate), can provide high current instantaneously</td>
      <td>Lower discharge rates, suitable for stable power output</td>
      </tr>
      <tr>
      <th>Charging Time</th>
      <td>Supports fast charging but requires a dedicated charger</td>
      <td>Relatively slower charging time</td>
      </tr>
      <tr>
      <th>Safety</th>
      <td>More susceptible to physical damage or overcharging, risk of fire</td>
      <td>Relatively safer, resistant to overcharge and overdischarge</td>
      </tr>
      <tr>
      <th>Shape and Flexibility</th>
      <td>Can be made in various shapes and sizes, high flexibility in fitting space</td>
      <td>Fixed cylindrical shape, less adaptable to different spaces</td>
      </tr>
      <tr>
      <th>Internal Resistance and Efficiency</th>
      <td>Lower internal resistance, suitable for high current discharge, high efficiency</td>
      <td>Relatively higher internal resistance, slightly lower efficiency</td>
      </tr>
      <tr>
      <th>Lifecycle</th>
      <td>Shorter lifespan, fewer charge cycles (typically 300-500 cycles)</td>
      <td>Longer lifespan, more charge cycles (typically 500-1000 cycles)</td>
      </tr>
      <tr>
      <th>Application Scenarios</th>
      <td>Used in drones, RC vehicles, and applications requiring high output</td>
      <td>Used in laptops, power banks, and applications needing stable power supply</td>
      </tr>
      <tr>
      <th>Cost</th>
      <td>Relatively more expensive, requires dedicated charging equipment</td>
      <td>Relatively cheaper</td>
      </tr>
    </tbody>
  </table>

   - As shown in the table above, the 3S Li-Polymer (LiPo) battery has advantages of high output current, high energy density, and a lightweight design, making it particularly suitable for applications that require high instantaneous current, such as drones and RC vehicles. Therefore, we decided to select the __3S Li-Polymer battery (LiPo)__ as the power source for the autonomous vehicle in this competition.
   - Our experience with 3S Li-Po batteries has shown that their safety is a significant concern. Improper charging practices have led to battery fires, and incorrect storage has resulted in battery damage. These incidents underscore the importance of following strict guidelines for handling these batteries.
  <div align=center>
  <table>
  <tr>
  <th>Photo of 3S Li-Polymer (LiPo) battery burnout during charging.</th>
  </tr><tr>
  <td>battery burnout during charging</td>
  </tr>
  </table>
  </div>

 ### Step-Down power supply Module  Selection
   
   - The working voltage of controllers like the Nvidia Jetson Nano and Raspberry Pi Pico is 5V, while the 3S Li-Polymer battery we selected has a voltage of 12V. Therefore, a 12V to 5V step-down module is needed to reduce the voltage and protect the control board from high voltage damage.

   - Initially, we chose the LM2596 DC-DC adjustable step-down module because it displays output voltage values, which makes monitoring easier and ensures stable voltage throughout the competition. However, the module’s maximum output current is only 3A, which is insufficient for all devices.

   - As a result, we found the 5A Constant Voltage Constant Current Buck Power Supply Module online, with a maximum output current of 5A, which is sufficient to support the normal operation of the autonomous vehicle. Although this module does not have a voltage display function, a battery low-voltage alarm can be used to monitor the battery voltage, ensuring adequate power levels.
  
- #### Step-Down power supply Module Comparison
  <div align="center">
  <table with=100%>
  <tr align="center">
  <th rowspan="2">Photo</th>
  <th> LM2596 DC-DC Adjustable Buck Module LM2596 DC-DC </th>
  <th>5A Constant Voltage Constant Current Buck Power Supply Module ADIO-DC36V5A</th>
  </tr>
  <tr align="center">
  <td>LM25  </td>
  <td>ADIO-DC36V5A 
  </td>
  </tr>
  <tr >
  <th>Specification</th>
  <td>
  <ol>
    <li>Module Type: Non-isolated Buck (Step-down)</li>
    <li>Input Voltage Range: 3.2V - 40V</li>
    <li>Output Voltage Range: 1.25V - 35V, with a maximum output current of 3A</li>
    <li>Maximum Output Current: 3A</li>
    <li>Voltage Regulation: Input voltage range of 4V - 40V</li>
    <li><a href="https://www.amazon.ae/UIOTEC-Converter-Digital-Step-up-Voltage/dp/B074LX3YYT" target="_blank">website</a> </li>
    </ol>
   </td>
   <td>
   <ol>
    <li>Input Voltage Range: 4 - 38V</li>
    <li>Output Voltage Range: 1.25 - 36V, continuously adjustable</li>
    <li>Output Current Range: Adjustable, maximum of 5A</li>   
    <li><a href="https://shop.cpu.com.tw/product/57434/info/" target="_blank">website</a></li>
    </ol>
    </td>
    </tr>
    </table>
    </div>
 
### Charging/Discharging Equipment and Li-Polymer Battery Low Voltage Alarm.
  - To protect the 3S Li-Polymer (LiPo) battery from damage during use and storage and to extend its lifespan, we implemented the following strategies:
    - __Use a Dedicated Charger:__ Choose a balanced charger suitable for LiPo batteries to ensure each cell’s voltage remains balanced, preventing damage due to overcharging or unbalanced charging.
    <div align="center">
    <table>
    <tr align="center">
    <th colspan="3">Dedicated Charger(Charging/Discharging Equipment)</th>
    </tr>
    <tr align="center">
    <th>Skyrc E430</th>
    <th>Skyrc Imax B6C2 v2</th>
    <th>HOTA D6 Pro</th>
    </tr>
    <tr>
    <td></td>
    <td></td>
    <td></td> 
     </tr>
     </table>
     </div>      

    - __Monitor the Charging Process:__ Supervise the battery during charging, avoiding extended periods without monitoring to quickly detect and resolve any charging abnormalities.

    - __Control Charging Voltage and Current:__ Keep the charging voltage below the standard 4.2V per cell and maintain an appropriate charging current to prevent damage from fast charging.

    - __Avoid Over-Discharge:__ During use, ensure each cell’s voltage does not drop below 3.0V to prevent over-discharge, which could damage the battery and reduce its lifespan.

    - __Safe Storage:__ When not in use, store the battery in a fireproof bag or a dedicated safety container to avoid damage from external pressure or high temperatures.

    - __Storage Voltage:__ For long-term storage, charge the battery to around 50% (3.7V-3.85V per cell) to extend its lifespan and reduce the risk of self-discharge.

    - __Keep Away from High Temperatures:__ Avoid using or storing the battery in high-temperature environments, as heat accelerates aging and increases the risk of damage and fire.

    - __Regular Battery Checks:__ Inspect the battery regularly for appearance and voltage. If swelling, cracking, or voltage abnormalities are detected, immediately stop using and dispose of it safely.

  - #### Low Voltage Alarm       
      
      <div align="center">
       <table>
       <th colspan="2">Li-Polymer Battery Low Voltage Alarm </th>
       <tr>
       <td>Installing a low-voltage alarm on the battery can emit an audible warning when the voltage falls below a set value, alerting the user to monitor or replace the battery in time. This effectively prevents insufficient power issues during competitions and protects the battery from damage due to over-discharge.</td>
        <td>low_voltage_alarm</td>
       </tr>
       </table>
       </div>

# <div align="center">HOME[Return Home](../../)</div>

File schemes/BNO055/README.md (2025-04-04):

，<div align="center">logo</div>

## <div align="center">Gyroscope orientation sensor Introduction</div> 

- ### __Instruction to BNO055 Gyroscope orientation sensor__
    <div align="center">
    <table>
    <tr>  
    <td>
    <ol>
        <li>The BNO055 gyroscope orientation sensor is a high-precision nine-axis absolute orientation sensor developed by Bosch Sensortec. It integrates an accelerometer, gyroscope, and magnetometer and has a built-in microprocessor for sensor fusion algorithms, providing real-time attitude and orientation information. Its primary feature is automatic sensor calibration, enabling it to directly output absolute orientation data in three-dimensional space.
        </li>
        <li>The BNO055 gyroscope orientation sensor can provide data on azimuth, tilt angle, acceleration, angular velocity, and magnetic field strength, making it ideal for applications that require precise attitude and orientation sensing, such as autonomous driving, robotic navigation, virtual reality (VR) devices, and various industrial control systems. With its built-in sensor fusion technology, the BNO055 gyroscope orientation sensor simplifies system design, relieving developers from handling complex data fusion.
        </li>
        <li>This sensor supports multiple interfaces (e.g., I2C, UART), allowing for easy integration into different embedded systems. The BNO055 gyroscope orientation sensor’s built-in algorithm automatically adjusts to provide stable readings across different environments, making it suitable for applications requiring high stability and accuracy.
    </ol>
    </td>
    <td width=300 align="center">
      BNO055up
      BNO055

    </td>
    </tr>
    </table>
    </div>

    We installed the BNO055 gyroscope orientation sensor on the vehicle and connected it to the Nvidia Jetson Nano controller, using I2C mode for data transmission. This setup is used to read the vehicle's current orientation, and the obtained orientation data is transmitted to the main program for calculation and analysis, serving as a basis for the vehicle's steering decisions.

  - #### Hardware Connection:
    **Power Supply:**

    - Connect VDD (BNO055) to the 3.3V pin on the Raspberry Pi Pico (pin 36). The BNO055 operates within a voltage range of 2.4V to 3.6V, and the Raspberry Pi Pico’s 3.3V pin provides a stable 3.3V voltage, making it suitable for powering the BNO055.
    - Connect GND (BNO055) to one of the GND pins on the Raspberry Pi Pico(pin 8) to ensure a common ground between the two devices.
     
    **I²C Communication:**

    - Connect SDA (BNO055) to the SDA pin on the Jetson Nano (pin 3 on header J41).
    - Connect SCL (BNO055) to the SCL pin on the Jetson Nano (pin 5 on header J41).
    - Connect both PS0 and PS1 pins (BNO055) to ground (GND) to set the device to I²C mode.
    - Connect the ADD pin (BNO055) to ground (GND) to set the I²C address to 0x28.

- The following is __Python__ code that implements orientation detection functionality from the __BNO055 gyroscope sensor__ on an __Nvidia Jetson Nano__ using a class-based approach.

    - ####  Python code

            import time
            from Adafruit_BNO055 import BNO055
            class BNO055Sensor:
                def __init__(self, i2c_address=0x28):
                    # Initialize BNO055 sensor with the specified I2C address
                    self.bno = BNO055.BNO055(i2c_address=i2c_address)
                    
                    # Check if the sensor was initialized successfully
                    if not self.bno.begin():
                        raise RuntimeError("Failed to initialize BNO055. Please check the connection.")
                    else:
                        print("BNO055 initialized successfully.")

                def get_orientation(self):
                    # Read orientation (Heading, Roll, Pitch) from the sensor
                    heading, roll, pitch = self.bno.read_euler()
                    return {
                        "heading": heading,
                        "roll": roll,
                        "pitch": pitch
                    }

                def get_calibration_status(self):
                    # Retrieve calibration status for the system, gyroscope, accelerometer, and magnetometer
                    sys, gyro, accel, mag = self.bno.get_calibration_status()
                    return {
                        "system": sys,
                        "gyroscope": gyro,
                        "accelerometer": accel,
                        "magnetometer": mag
                    }

    - #### Example usage
            sensor = BNO055Sensor()
            while True:
                # Get orientation data
                orientation = sensor.get_orientation()
                print("Orientation - Heading: {heading}°, Roll: {roll}°, Pitch: {pitch}°".format(**orientation))

                # Get calibration status
                calibration_status = sensor.get_calibration_status()
                print("Calibration Status:", calibration_status)

                time.sleep(1)

   - #### Explanation    
        <p>
        <ol>
        <li><strong>__init__ method:</strong> Initializes the BNO055 Gyroscope orientation Sensor class, setting the I2C address and verifying the sensor connection. If the connection fails, it raises an error.</li>
        <li><strong>get_orientation method:</strong> Retrieves orientation data from the sensor (Heading, Roll, and Pitch) and returns them in a dictionary.
        get_calibration_status method: Returns the calibration status for the system, gyroscope, accelerometer, and magnetometer, which is useful for ensuring accurate measurements.</li>
        </ol></p>

      __This code reads and prints the BNO055 Gyroscope orientation sensor's orientation data and calibration status every second.__

# <div align="center">HOME[Return Home](../../)</div>

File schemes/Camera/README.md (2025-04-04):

<div align="center">logo</div>

## <div align="center">Camera Selection</div> 
  <ol><li>To enable a vehicle to accurately detect obstacles on the track, the selection of a camera module has become a key factor influencing competition outcomes. Choosing a high-resolution, low-latency, high-sensitivity camera module can improve image clarity and enhance the vehicle’s ability to recognize obstacles, allowing for more precise obstacle avoidance and navigation maneuvers. This directly impacts the performance of autonomous vehicles in competitions.</li>
  <li>Previously, we used the Nvidia Jetson Nano as the main controller, so it is necessary to select a camera module compatible with the Nvidia Jetson Nano to ensure proper functionality. Below is a comparison of commonly used camera modules in Taiwan.</li>
  </ol>

- ### Comparison of Camera Modules
    <div align="center">
    <table>
    <tr align="center" >
    <th rowspan="2">Model</th> 
    <th >SONY IMX219</th>
    <th >SONY IMX477</th>
    </tr>
    <tr align="center">
    <td>SONY IMX219</td>
    <td>SONY IMX477</td>
    </tr>
    <tr align="center">
    <td>Sensor</td>
    <td>SONY IMX 219</td>
    <td>SONY IMX 477</td>
    </tr>
    <tr align="center">
    <td>FOV</td>
    <td>160 MAX</td>
    <td>160 MAX</td>
    </tr>
    <tr align="center">
    <td>Resolution</td>
    <td>3280 × 2464 pix</td>
    <td>4056 × 3040 pix</td>
    </tr>
    </tr>
    </table>
    </div>

    __From this, it is clear that in terms of resolution, the SONY IMX 477 is our best choice for the competition environment.__

- ### Wide-angle lens distortion correction
  The purpose of wide-angle lens distortion correction is to reduce or eliminate the deformation effects produced when capturing images with a wide-angle lens. These deformations often include "barrel distortion" or "pincushion distortion," which cause straight objects in the image to appear curved or distorted. Through correction, images can be restored to proportions and shapes closer to reality, enhancing the accuracy and realism of the image. This is particularly suitable for applications requiring precise measurement or detailed capture, such as machine vision, architectural surveying, and autonomous driving technology.
  - ### Correction Methods
    To perform wide-angle lens distortion correction on the Nvidia Jetson Nano, the correction functions in the OpenCV library are commonly used. Here are the basic steps:
    <ol>
    <li>
    <strong>Capture Calibration Images:</strong> Place a checkerboard or dot array within the field of view of the wide-angle lens and capture multiple images from different angles. These images are used to calculate calibration parameters.</li>
        <div align="center">
    <table>
    <tr align="center" >
    <th >Checkerboard Image</th> 
    </tr>
    <tr align="center">
    <td>Chessboard</td>
    </tr>  
    </table>
    </div>
    <li>
    <strong>Detect Checkerboard Corners:</strong> Use OpenCV's findChessboardCorners() function to automatically detect the corner positions of the checkerboard. For each calibration image, this step finds the corner coordinates needed for calculating the correction parameters.</li>
    Calculate Calibration Parameters: Use the calibrateCamera() function to calculate the camera's intrinsic parameters and distortion coefficients. These parameters include focal length, optical center, and radial and tangential distortion coefficients of the lens.</li>
    <li>
    <strong>Apply Correction Parameters:</strong> In actual images, use the undistort() function to apply the correction parameters to each frame. This corrected image will reduce the distortion caused by the wide-angle lens, making the image closer to true proportions.</li>
    <li>
    <strong>Real-Time Processing (If Needed):</strong> If real-time correction is required on the Jetson Nano, ensure efficiency in image processing. Given the limited performance of the Jetson Nano, consider adjusting image resolution or optimizing processing steps to enhance correction speed.</li>
    </ol>

    __A simple code example is as follows:__
    - ### python Code

          import cv2
          import numpy as np

          # Load calibration images
          images = ["image1.jpg", "image2.jpg", ...]  # Replace with your image paths
          chessboard_size = (9, 6)  # Chessboard dimensions
          obj_points = []  # Real world coordinates points
          img_points = []  # Image coordinates points

          # Define corner points for the chessboard
          objp = np.zeros((chessboard_size[0] * chessboard_size[1], 3), np.float32)
          objp[:, :2] = np.mgrid[0:chessboard_size[0], 0:chessboard_size[1]].T.reshape(-1, 2)

          for image in images:
              img = cv2.imread(image)
              gray = cv2.cvtColor(img, cv2.COLOR_BGR2GRAY)
              ret, corners = cv2.findChessboardCorners(gray, chessboard_size, None)
              
              if ret:
                  img_points.append(corners)
                  obj_points.append(objp)

          # Calibrate camera parameters
          ret, mtx, dist, rvecs, tvecs = cv2.calibrateCamera(obj_points, img_points, gray.shape[::-1], None, None)

          # Read the image to be undistorted
          img = cv2.imread('test_image.jpg')
          h, w = img.shape[:2]
          newcameramtx, roi = cv2.getOptimalNewCameraMatrix(mtx, dist, (w,h), 1, (w,h))

          # Apply distortion correction
          dst = cv2.undistort(img, mtx, dist, None, newcameramtx)

          # Crop the image
          x, y, w, h = roi
          dst = dst[y:y+h, x:x+w]

          cv2.imshow('Undistorted Image', dst)
          cv2.waitKey(0)
          cv2.destroyAllWindows()

      Experimental results indicate that setting the resolution to __640x480__ optimizes system performance. This configuration effectively reduces the computational load on the Jetson Nano while significantly enhancing the efficiency of image capture and recognition.  
     ### Comparison image of before and after correction.
    
    <div align="center">
    <table>
    <tr align="center" >
    <th>Item</th>
    <th >Before</th>
    <th >After</th>
    </tr>
    <tr align="center">
    <th>Photo</th>
    <td>Camera_Before</td>
    <td>Camera_After</td>
    </tr>
    </table>
    </div>
# <div align="center">HOME[Return Home](../../)</div>

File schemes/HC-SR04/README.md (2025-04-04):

，<div align="center">logo</div>

## <div align="center">Ultrasonic rangefinder Introduction</div> 

- ### __Instruction to HC-SR04 ultrasonic distance sensor__
    <div align="center">
    <table>
    <tr>  
    <td>
    <ol>
        <li>The HC-SR04 ultrasonic distance sensor is a cost-effective and user-friendly solution for distance measurement. It operates by transmitting ultrasonic pulses and measuring the time of flight to determine the distance to an object. With a measurement range of 2cm to 400cm and a precision of 3mm, it provides highly accurate and reliable distance data, making it suitable for a wide range of applications including obstacle avoidance, autonomous navigation, and object detection.
        </li>
        <li>The HC-SR04 ultrasonic distance sensor helps us detect the distance between the vehicle and the side wall when entering the parking area, facilitating parking maneuvers. By programming precise control based on the detected distance, we can guide the vehicle into the parking area smoothly, helping us successfully complete the task.
        </li>

    </ol>
    </td>
    <td width=300 align="center"><p>
    <strong>Supports 3.3V operating voltage</strong>
    </p>
        HC-SR04
        HC-SR04
    </td>
    </tr>
    </table>
    </div>
   <ol>
    <li>We installed HC-SR04 ultrasonic distance sensors on the left, right, and rear of the vehicle and connected them to the Raspberry Pi Pico controller to detect the distance between the vehicle and the side walls. The measured distance data is transmitted to the main program for processing, serving as a basis for parking maneuvers.</li>
    <li>It is worth noting that the maximum signal voltage read by the Raspberry Pi Pico controller is 3.3V, while commercially available HC-SR04 ultrasonic distance sensors typically output a maximum signal voltage of 5V. Therefore, when selecting or using the sensor, special attention should be paid to its operating voltage to avoid operational issues or potential damage to the controller due to voltage mismatch.</li>
    </ol>
<br>
    <div align="center" width=100%>
    <table >
    <tr align="center">
    <th colspan="4">HC-SR04 Ultrasonic Distance Sensor Placement Diagram on Vehicle</th>
    </tr>
    <tr align="center">
      <th>Left</th>
      <th>Right</th>
      <th colspan="2">Rear</th>
      </tr>
    <tr>
      <td>HC-SR04</td>
      <td>HC-SR04</td>
      <td>HC-SR04</td>
      <td>HC-SR04</td>
      </tr>
    </table>
    </div>

   - #### Wiring steps for connecting the HC-SR04 to the Raspberry Pi Pico:

        - VCC (HC-SR04) connects to the 3.3V (pin 36) on the Raspberry Pi Pico: Provides power to the ultrasonic sensor.
        - GND (HC-SR04) connects to the GND pin on the Raspberry Pi Pico: Ensures a common ground between both devices.
        - Trig (HC-SR04) connects to the GPIO pins on the Raspberry Pi Pico:
            - pin 18 (left),
            - pin 16 (right),
            - pin 6 (rear), used for sending ultrasonic pulse signals.
        - Echo (HC-SR04) connects to the GPIO pins on the Raspberry Pi Pico:
            - pin 12 (left),
            - pin 17 (right),
            - pin 7 (rear), used for receiving the echo signal.
    
 - Below is the code written in MicroPython, implemented as a class to read the detection distance from the HC-SR04 ultrasonic sensor using the Raspberry Pi Pico.
   - #### MicroPython code 
            from machine import Pin, time_pulse_us
            import time
            class HCSR04:
                def __init__(self, trigger_pin, echo_pin, echo_timeout_us=30000):
                    self.trigger = Pin(trigger_pin, Pin.OUT)
                    self.echo = Pin(echo_pin, Pin.IN)
                    self.echo_timeout_us = echo_timeout_us
                    self.trigger.low()
                    time.sleep(0.05)  # Stabilize the sensor

                def distance_cm(self):
                    # Send a 10us pulse to trigger the measurement
                    self.trigger.high()
                    time.sleep_us(10)
                    self.trigger.low()

                    # Wait for the echo response and measure its duration
                    try:
                        pulse_time = time_pulse_us(self.echo, 1, self.echo_timeout_us)
                    except OSError as ex:
                        pulse_time = -1

                    # Calculate distance in cm (pulse time in microseconds)
                    if pulse_time > 0:
                        distance = (pulse_time / 2) / 29.1  # Speed of sound ~343 m/s
                    else:
                        distance = -1  # Return -1 if timeout or error

                    return distance
  
   - #### Example usage  

            sensor = HCSR04(trigger_pin=3, echo_pin=2)  # Assign pins accordingly
            while True:
                distance = sensor.distance_cm()
                if distance == -1:
                    print("Out of range or error")
                else:
                    print("Distance: {:.2f} cm".format(distance))
                time.sleep(1)
   - #### Explanation  
        This code includes a class named <strong>HC-SR04</strong> that measures distance by defining trigger and echo pins. The distance_cm() method returns the distance in centimeters, and if a measurement error occurs or the distance is out of range, it returns -1.

# <div align="center">HOME[Return Home](../../)</div>

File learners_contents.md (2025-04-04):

<div align="center">logo</div> 

## For Learners ## 

- ### Hardware Selection
    - [Main Controller Comparison](./schemes/Main_Controller_Choosing/README.md)
    - [Motor & Sensor Intermediate I/O Controller Comparison](./schemes/Motor_Sensor_Controller_Choosing/README.md)
    - [Moter Selection](./schemes/Motor/README.md)
    - [Ultrasonic rangefinder](./schemes/HC-SR04/README.md)
    - [Gyroscope orientation sensor](./schemes/BNO055/README.md)
    - [Camera Selection](./schemes/Camera/README.md)
    
- ### Vehicle Design
    - [Vehicle 2D/3D Models in CAD](./models/Vehicle_2D_3D/README.md)
    - [BOM Parts List](./schemes/Parts_List/README.md)
    - [Vehicle Chassis Design](./schemes/Vehicle_Chassis_Design/README.md)
    - [Circuit Design](./models/Circuit_Design/README.md)
    - [Hardware Fool-Proof Design](./schemes/Fool-Proof-Design/README.md) 
    - [Assembly Instructions & Wiring Diagrams](./schemes/Assembly_Instructions/README.md)
    - __power Management__
      - [Battery choice for self-driving cars](./schemes/Battery/README.md)
      - [Power Supply System](./schemes/Power_Supply_System/README.md) 
- ### System Initialization
    - [OpenCV Introduction](./src/OpenCV/README.md)
    - [Software Platform Construction](./src/System_Platform_Software/README.md)
- ### Obstacle Management
    - __Image Recognition Processing and Steering__
      - [Image Recognition Processing](./src/Image_Recognition_Processing/README.md)  
      - [Steering Control](./src/Steering_Control/README.md)  
      - [Automatically record the HSV values of the field](src/Automatically_record_HSV/README.md)
    - __Programming__
      - [Open Challenge Code Overview](./src/Programming/Open_Challenge/README.md)
      - [Obstacle Challenge Code Overview](./src/Programming/Obstacle_Challenge/README.md)
      - [Distinctive Pseudo Code](./src/Distinctive_Pseudo_Code/README.md)
      - [Parking Instruction](./src/parking/README.md)
      - [NoMachine Introduction](./other/NoMachine/README.md)
- ### Pictures – Team and vehicle
    - [Team Members Introduction](./t-photos/README.md) 
    - [Vehicle Photos](./v-photos/README.md) 
- ### Performance videos
    - [Open Challenge](./video/Open_Challenge/video.md)
    - [Obstacle Challenge](./video/Obstacle_Challenge/video.md)
    - [Self-Driving Car Design Process Video](./video/Design_Process_Video/video.md)
- ### GitHub Utilization
    - [GitHub Edit(VScode Edit/GIT)](./src/GitHub_Edit/README.md)
    - [GitHub Web Editing Languages](./src/GitHub_Languages/README.md)
- ### Work Dairy
    - [March](./other/work_diary/README.md#20240304--20240310)
    - [April](./other/work_diary/README.md#20240401--20240407)
    - [May](./other/work_diary/README.md#20240429--20240505)
    - [June](./other/work_diary/README.md#20240527--20240602)
    - [July](./other/work_diary/README.md#20240701--20240707)
    - [August](./other/work_diary/README.md#20240729--20240804)
    - [September](./other/work_diary/README.md#20240826--20240901)
    - [October](./other/work_diary/README.md#20240930--20241006)
    - [November](./other/work_diary/README.md#20241028--20241103)
- ### ${{\color{red} Competition Schedule}} $  
# <div align="center">Gantt chart</div>

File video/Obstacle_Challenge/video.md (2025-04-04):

<div align="center">logo</div>

## <div align="center">Testing Video of Self-Driving Car in Obstacle Challenge</div>

- #### The last traffic light on the second lap is a green signal.(No need to turn around ) 

  Here is a test video of a vehicle on the second lap, with the last traffic light being green. 
  <div align="center">
  <table >
    <tr >
       <th align="center">The last traffic light on the second lap is a green signal</th>

    </tr>
    <tr >
       <td  width="500" ><a href="https://youtu.be/O4IrJlX9vzc">Obstacle Challenge noRed@Fire On All Cylinders</a> </td>

    </tr>
    </table>  
    </div>

- #### The last traffic light on the second lap is red.(Need to turn around)  

  Here are test videos of the last traffic light being red in different positions on the second lap.  

  <div align="center">
  <table >
    <tr >
       <th align="center">At Position 1</th>
       <th align="center">At Position 2</th>
       <th align="center">At Position 3</th>
    </tr>
    <tr >
       <td  width="500" ><a href="https://youtu.be/uUHdDcKv2U4">Obstacle-Challenge-Red1@Fire-On-All-Cylinders</a> </td>
       <td  width="500" ><a href="https://youtu.be/3C-JRB5SZuY">Obstacle-Challenge-Red2@Fire-On-All-Cylinders</a> </td>
       <td  width="500" ><a href="https://youtu.be/zOrth1XzHYA">Obstacle-Challenge-Red3@Fire-On-All-Cylinders</a> </td>
    </tr>
    </table>  
    </div>

- #### Video of parking tests at different positions.
  
  <div align="center">
  <table >
    <tr >
       <th align="center">Position is on the Left</th>
       <th align="center">Position is at the top</th>
       <th align="center">Position is on the right</th>
       <th align="center">Position is at the bottom</th>
    </tr>
    <tr >
       <td  width="500" ><a href="https://youtu.be/N71LAlh8o_8">parking Left@Fire-On-All-Cylinders</a> </td>
       <td  width="500" ><a href="https://youtu.be/NonpbOTjr0Y">parking Top@Fire-On-All-Cylinders</a> </td>
       <td  width="500" ><a href="https://youtu.be/3ksQ_JbKirA">parking Right@Fire On All Cylinders</a> </td>
       <td  width="500" ><a href="https://youtu.be/Pm028mA2RkY">parking Down@Fire-On-All-Cylinders</a> </td>
    </tr>
    </table>  
    </div>

 - ### Explanation to Obstacle Challenge

  <div align="center">
  <table >
    <tr >
       <th align="center">ALL Fire On All Cylinders</th>
    </tr>
    <tr >
       <td  width="500" ><a href="https://youtu.be/pB6wAqTKomQ">ALL Fire On All Cylinders</a> </td>
    </tr>
    </table>  
  </div>

# <div align="center">HOME[Return Home](../../)</div>

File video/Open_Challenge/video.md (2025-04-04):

<div align="center">logo</div>

## <div align="center">Testing Video of Self-Driving Car in Open Challenge</div> 

  Here are test videos of vehicles in different power and field combinations.

- ### Full width

  This is a test video of a vehicle in a field set to "wide-wide-wide-wide".
<table>
  <tr align="center">
     <th>Power 50</th>
     <th>Power 70</th>    
  </tr>
  <tr >
     <td width="40%"><a href="https://youtu.be/m-hIjlLuAAk">Open Challenge power 50 Full width @ Fire-On-All-Cylinders</a> </td>
     <td width="40%"><a href="https://youtu.be/tObPuwR8IB0">Open Challenge power 70 Full width @ Fire-On-All-Cylinders</a></td>
  </tr>
  </table>

- ### Half-width half-narrow
 
  This is a test video of a vehicle in a "wide-narrow-wide-narrow" field configuration, which is more difficult.
<table>
  <tr align="center">
     <th>Power 50</th>
     <th>Power 70</th>    
  </tr>
  <tr >
     <td width="40%"><a href="https://youtu.be/UB3IciF5oYk">Open Challenge power 50 half width half height width @ Fire On All Cylinders</a> </td>
     <td width="40%"><a href="https://youtu.be/SKT1LZI2bo0">Open Challenge power 70 half width half height width @ Fire On All Cylinders</a></td>
  </tr>
  </table>

- ### Full narrow
  This is a testing video of the vehicle on a course set as 'narrow-narrow-narrow-narrow.' As all road widths have been reduced, this results in a limited correction space for the machine, making it easy for it to overshoot during turns and potentially collide with the walls.
<table>
  <tr align="center">
     <th>Power 50</th>
     <th>Power 70</th>    
  </tr>
  <tr >
     <td width="40%"><a href="https://youtu.be/cyHyQRcBAyE">Open Challenge power 50 full narrow @ Fire On All Cylinders</a> </td>
     <td width="40%"><a href="https://youtu.be/OmFEYUQlTvc">Open Challenge power 70 full narrow @ Fire On All Cylinders</a></td>
  </tr>
  </table>  

- ### wide narrow wide narrow

  These are test videos of a vehicle in a "wide-narrow-wide-narrow" field configuration, recorded clockwise and counterclockwise.
<table>
  <tr align="center">
     <th>Clockwise</th>
     <th>Counter Clockwise</th>    
  </tr>
  <tr >
     <td width="40%"><a href="https://youtu.be/WJuGyNkQvu4">Open Challange clockwise @ Fire On All Cylinders</a> </td>
     <td width="40%"><a href="https://youtu.be/na2J1C6Xs2s">Open Challange Countclockwise @ Fire On All Cylinders</a></td>
  </tr>
  </table>  

# <div align="center">HOME[Return Home](../../)</div>

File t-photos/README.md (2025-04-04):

<div align="center">logo</div>

## <div align="center"> Team Members Introduction</div>
- ### Team Photo  

  - Today is the first day that our team was established, so I took a photo to commemorate it. The location was chosen in the club classroom.

<div align="center">

|Team Photo|</div>  

- ### Funny Photo
  - This is our attempt to take a photo using the method of stacking Arhats. In fact, the angle of our back is a bit wrong and we almost slipped down.

<div align="center">Funny Photo </div>  

## Team Members of Introduction  

<table>
  <tr align="center">
     <th>Personal photo</th>
     <th>Work photo</th>    
  </tr>
  <tr >
      <td align="center">HU,SIAN-YI</td>
      <td align="left">Work Assignments：<br>
         <ol><li>primarily responsible for writing Code </li>
             <li>Assist in vehicle circuit design </li>
         </ol>
      </td>
  </tr>

  <tr align="center">
      <td>HU </td>
      <td>Hu WORK</td>
  </tr>
    <tr align="center">
     <th>Personal photo</th>
     <th>Work photo</th>    
  </tr>
  <tr align="center">
     <td>LAI,MENG-CHENG</td>
     <td align="left">Work Assignments：<br>
         <ol><li>primarily responsible for  vehicle hardware integration </li>
             <li>Assist in writing Code </li>
         </ol>
     </td>    
  </tr>

  <tr align="center">
      <td>mo </td>
      <td>mo WORK</td>
  </tr>
    <tr align="center">
     <th>Personal photo</th>
     <th>Work photo</th>    
  </tr>
   <tr>
     <td align="center">HUANG,KE-FU</td>
     <td align="left">Work Assignments：<br>
         <ol><li>primarily responsible for  writing Code Report recording and writing.</li>
             <li>Assist in vehicle hardware design.  </li>
         </ol>
     </td>    
  </tr>

  <tr align="center">
      <td>FU </td>
      <td>Fu WORK</td>
  </tr>
</table>

# <div align="center">HOME[Return Home](../)</div>

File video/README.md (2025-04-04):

<div align="center">logo</div>

# <div align="center">Demonstration Video  </div> 

## [連至影片 Video.md](video.md)  

> 此目錄必須包含 video.md 文件，其中包含顯示車輛自動駕駛的 YouTube URL（應該是公共的或可通過鏈接訪問）。視頻中存在駕駛演示的部分長度必須至少為 30 秒。

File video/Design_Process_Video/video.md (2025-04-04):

<div align="center">logo</div>

## <div align="center">Self-Driving Car Design Process Video </div> 
<div align="center">
The following video showcases the vehicle design and mission testing process.

   |Self-Driving Car Design Process Video|
   |:----:|
   |Self-Driving Car Design Process Video (https://youtu.be/5BeNLBiUbT4 "Self-Driving Car Design Process Video")|
</div>

# <div align="center">HOME[Return Home](../../)</div>

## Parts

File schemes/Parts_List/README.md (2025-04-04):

<div align="center">logo</div>  

## <div align="center">BOM Part List </div>
<li><a href="https://robotkingdom.com.tw/product/rk-nvidia-jetson-nano-developer-b01/" target="_blank">NVIDIA® Jetson Nano™ developer-b01</a></li> 
<li><a href="https://piepie.com.tw/product/raspberry-pi-pico-w" target="_blank">Raspberry Pi Pico W RP2040</a></li> 
<li><a href="https://atceiling.blogspot.com/2019/08/arduino54l293d.html" target="_blank">L293d motor controller</a></li>
<li><a href="https://www.amazon.com/-/zh_TW/MG513-12V-%E6%B8%9B%E9%80%9F%E9%BD%92%E8%BC%AA%E9%A6%AC%E9%81%94%E7%B7%A8%E7%A2%BC%E5%99%A8%E4%BB%A3%E7%A2%BC%E9%80%9F%E5%BA%A6%E6%B8%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">	MG513-P20 549RPM DC reduction motor</a></li>  
<li><a href="https://shopee.tw/%E7%A3%9A%E5%AE%B6-LEGO-%E6%A8%82%E9%AB%98-%E9%BB%91%E8%89%B2-Technic-Gear-20-Tooth-20%E9%BD%92-%E9%BD%92%E8%BC%AA-%E9%9B%99%E6%96%9C%E9%BD%92-3226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">20-tooth Plastic gear<br></li>
<li><a href="https://shopee.tw/%E7%A3%9A%E5%AE%B6-LEGO-%E6%A8%82%E9%AB%98-%E7%A0%82%E8%89%B2-Technic-Gear-12-Tooth-Bevel-12%E9%BD%92-%E9%BD%92%E8%BC%AA-%E6%96%9C%E9%BD%92-6589-i.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">12-tooth Plastic gear<br></li>
<li><a href="https://www.amazon.com/-/zh_TW/dp/B0BFQLNDPM">MG90s servo motor</a></li>    
<li><a href="https://www.amazon.com/-/zh_TW/PLKXSEYUJ/dp/B0D4HZFM6S">Micro switch 6*6*10</a></li>  
<li><a href="https://www.amazon.in/Invento-Battery-Voltage-Indicator-Checker/dp/B072V44Q5Z">Lipo battery low voltage alarm </a></li>  
<li><a href="https://shopee.tw/%E8%BF%B7%E4%BD%A0%E8%88%B9%E5%9E%8B%E9%96%8B%E9%97%9C-10*15-%E8%88%B9%E5%9E%8B%E9%96%8B%E9%97%9C-%E8%BF%B7%E4%BD%A0%E9%96%8B%E9%97%9C-%E6%96%B9%E5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" target="_blank">Ship-type switch</a></li>     
<li><a href="https://shopee.tw/%E7%8F%BE%E8%B2%A8-SONY-IMX477-%E6%94%9D%E5%BD%B1%E9%8F%A1%E9%A0%AD%E6%A8%A1%E7%B5%84-1230%E8%90%AC%E5%83%8F%E7%B4%A0-160%C2%B0%E5%BB%A3%E8%A7%92-%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" target="_blank">SONY IMX477 camera module</a></li>
<li><a href="https://shopee.tw/product/17393576/2036942264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">Li-Polymer battery 3S Desire Power V8 11.1V 1300mAh 70C </a></li>
<li><a href="https://www.3dprow.com/products/%E6%AD%A3%E5%BB%A0-amass-xt60-xt60-f-xt60-m-%E9%8D%8D%E9%87%91%E9%AB%98%E9%9B%BB%E6%B5%81%E6%8E%A5%E9%A0%AD">Amass TX60-M plug
</a></li>
<li><a href="https://www.amazon.com/NOYITO-DC-DC-Power-Supply-Module/dp/B07G456MS8">High current 5A constant voltage constant current buck power supply module</a></li>  
<li><a href="https://www.ruten.com.tw/item/show?22229822791893">Lego 62821b Differential Gear<br></li>
<li>695ZZ bearing M5x13x4 NSK<br></li>
<li>Iron wire 1.2mm 1.2mm<br></li>
<li><a href="https://jin-hua.com.tw/webc/html/product/show.aspx?num=10130&page=1&kw=2.5mm&kind=945">2.5mm Connector 2 Pin Male Adapter Right Angle Pin Header White Socket<br></li>
<li><a href="https://jin-hua.com.tw/webc/html/product/show.aspx?num=36932&page=2&kw=2.5mm&kind=945">2.5mm Connector 3 Pin Male Adapter Right Angle Pin Header White Socket<br></li>
<li><a href="https://jin-hua.com.tw/webc/html/product/show.aspx?num=10126&page=2&kw=2.5mm&kind=945">2.5mm Connector 4 Pin Male Adapter Right Angle Pin Header White Socket<br></li>
<li><a href="https://jin-hua.com.tw/webc/html/product/show.aspx?num=10120&page=7&kw=2.5mm&kind=945">2.5mm Connector 6 Pin Male Adapter Right Angle Pin Header White Socket<br></li>
<li><a href="https://jin-hua.com.tw/webc/html/product/show.aspx?num=10092&page=7&kw=2.5mm&kind=944">2.5mm Connector 2 Pin female Adapter Right Angle Pin Header White Socket<br></li>
<li><a href="https://jin-hua.com.tw/webc/html/product/show.aspx?num=10087&page=7&kw=2.5mm&kind=944">2.5mm Connector 3 Pin female Adapter Right Angle Pin Header White Socket<br></li>
<li><a href="https://jin-hua.com.tw/webc/html/product/show.aspx?num=10084&page=7&kw=2.5mm&kind=944">2.5mm Connector 4 Pin female Adapter Right Angle Pin Header White Socket<br></li>
<li><a href="https://jin-hua.com.tw/webc/html/product/show.aspx?num=10078&page=7&kw=2.5mm&kind=944">2.5mm Connector 6 Pin female Adapter Right Angle Pin Header White Socket<br></li>
<li><a href="https://www.amazon.com/Plastic-Column-Standoff-Support-Male-Female/dp/B0D2HQ57N4?th=1">White Plastic Nylon M3x25+6mm Hex Column Standoff Support Male-Female<br></li>
<li><a href="https://www.amazon.com/Plastic-Column-Standoff-Support-Male-Female/dp/B0D2HPNSF9?th=1">White Plastic Nylon M3x15+6mm Hex Column Standoff Support Male-Female<br></li>
<li><a href="https://www.amazon.com/Plastic-Column-Standoff-Support-Male-Female/dp/B0D2HMNKDB?th=1">White Plastic Nylon M3x8 +6mm Hex Column Standoff Support Male-Female<br></li>
<li><a href="https://www.amazon.com/Plastic-Column-Standoff-Support-Male-Female/dp/B0D2HNQMZ9?th=1">White Plastic Nylon M3x6 +6mm Hex Column Standoff Support Male-Female<br></li>
<li><a href="https://www.amazon.com/Plastic-Column-Standoff-Support-Male-Female/dp/B0D2HLZK7D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">Internal Phillips Head Plastic screw M3x5mm<br></li>
<li><a href="https://www.amazon.com/Plastic-Column-Standoff-Support-Male-Female/dp/B0D2HNX9Q8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">Plastic Nut M3<br></li>
<li>Internal Hexagonal Metal Screw M3x10mm<br></li>
<li>Matal Nut M3<br></li>
<li>Matal Nut M2<br></li>
<li><a href="https://jin-hua.com.tw/webc/html/product/show.aspx?num=33200&kw=%e9%9b%bb%e6%9c%a8%e6%9d%bf&kind=522">PCB pegboard 30*30 900 holes<br></li>
<li><a href="https://phrozen3d.com.tw/products/rock-black-resin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">Light curing resin Rock-Black Stiff steering knuckle<br></li>
<li><a href="https://phrozen3d.com.tw/products/rock-black-resin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">Light curing resin Rock-Black Stiff drive shaft<br></li>
<li><a href="https://phrozen3d.com.tw/products/rock-black-resin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">Light curing resin Rock-Black Stiff gearbox<br></li>
<li><a href="https://phrozen3d.com.tw/products/speed-resin">Light curing resin Aqua-Gray 8K rudder<br></li>
<li><a href="https://phrozen3d.com.tw/products/speed-resin">Light curing resin Aqua-Gray 8K axle<br></li>
<li><a href="https://phrozen3d.com.tw/products/speed-resin">Light curing resin Speed motor bracket<br></li>
<li><a href="https://phrozen3d.com.tw/products/speed-resin">Light curing resin Speed windshield<br></li>
<li><a href="https://woodmall.com.tw/shop/product/3mm-s%e7%b4%9a%e7%99%bd%e4%bf%84%e6%a4%b4%e6%9c%a8%e6%9d%bf-60x90cm/">Wood board, thickness 3mm (bottom layer)<br></li>
<li><a href="https://woodmall.com.tw/shop/product/3mm-s%e7%b4%9a%e7%99%bd%e4%bf%84%e6%a4%b4%e6%9c%a8%e6%9d%bf-60x90cm/">Wood board, thickness 3mm (middle layer)<br></li>
<li><a href="https://woodmall.com.tw/shop/product/3mm-s%e7%b4%9a%e7%99%bd%e4%bf%84%e6%a4%b4%e6%9c%a8%e6%9d%bf-60x90cm/">Wood board, thickness 3mm (top layer)<br></li>
<li><a href="https://robotkingdom.com.tw/product/hc-sr04p-ultrasonic-ranger/">HC-SR04<br></li>
<li><a href="https://www.remisys.com.tw/product-page/bno055-absolute-orientation-sensor">BNO055<br></li>
<li><a href="https://shopee.tw/product/8434420/5734675597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">USB 3.0 Male to Female 90-Degree Angle Adapter<br></li>

# <div align="center">HOME[Return Home](../../)</div>

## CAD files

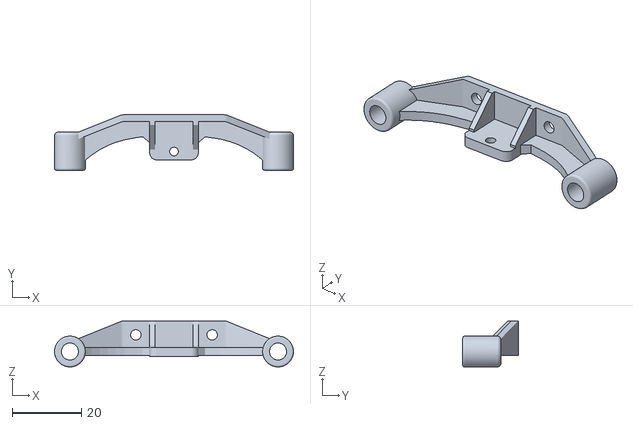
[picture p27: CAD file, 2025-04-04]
models/Vehicle_2D_3D/Vehicle_Chassis_CAD_File/Assembly.stl
68.9 x 16.0 x 13.2

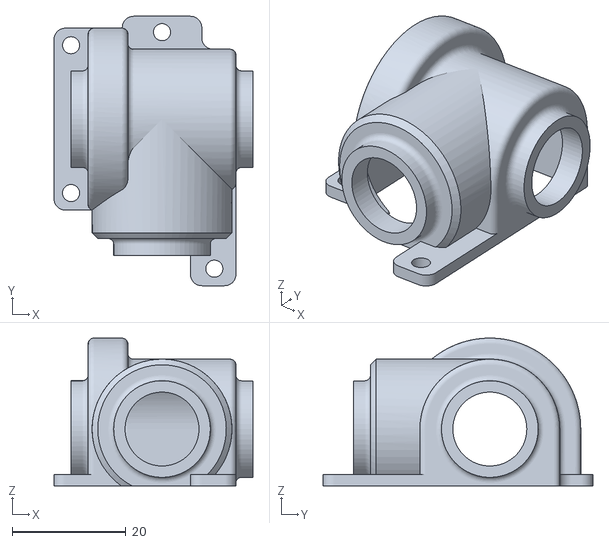
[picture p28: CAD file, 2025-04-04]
models/Vehicle_2D_3D/Vehicle_Chassis_CAD_File/Rear-differential-housing.stl
35.0 x 47.4 x 26.0

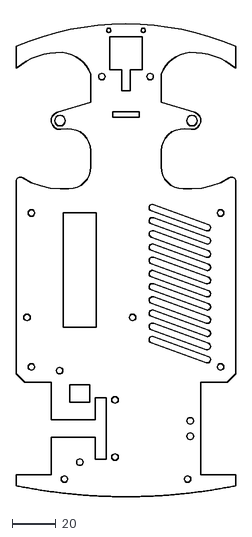
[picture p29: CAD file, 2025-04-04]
models/Vehicle_2D_3D/Vehicle_Chassis_Sizse/Vehicle Underfloor.dxf
100.0 x 218.4

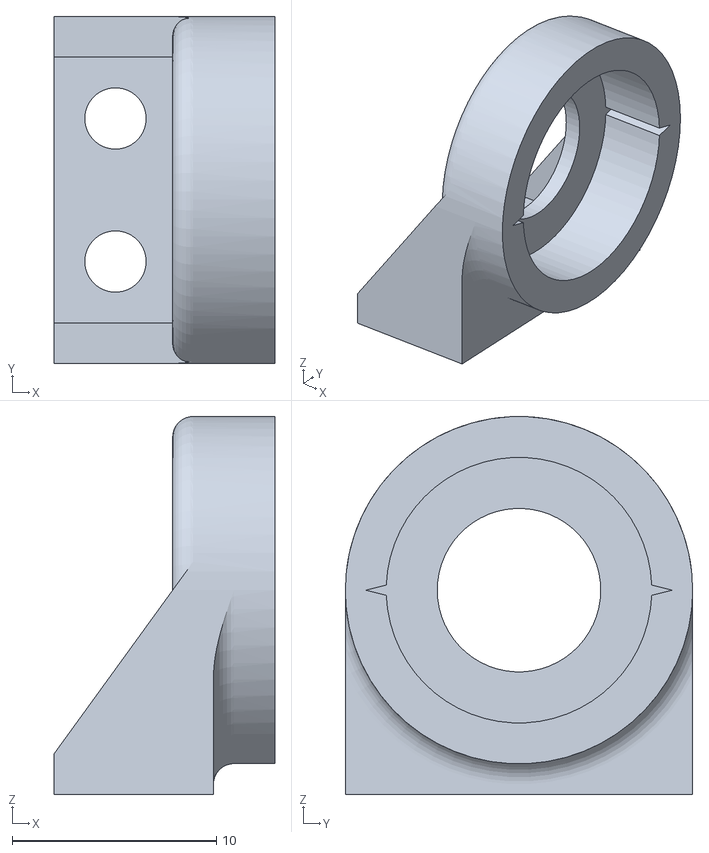
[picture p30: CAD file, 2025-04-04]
models/Vehicle_2D_3D/Vehicle_Chassis_CAD_File/Bearing-Holder.stl
10.8 x 17.0 x 18.5

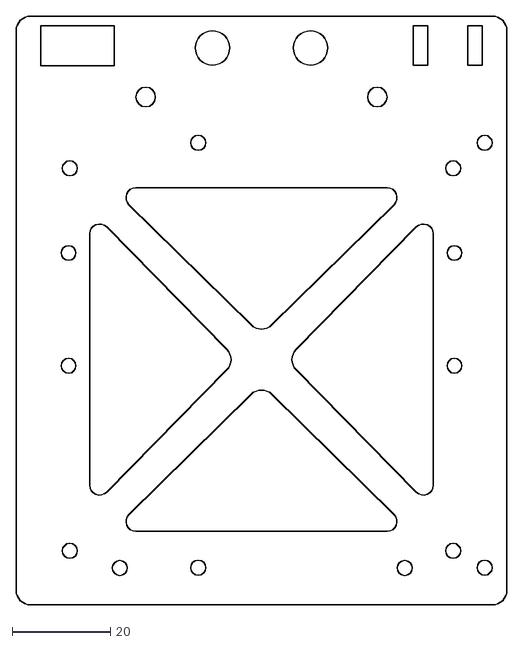
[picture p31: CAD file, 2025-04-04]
models/Vehicle_2D_3D/Vehicle_Chassis_Sizse/Vehicle_Top_Deck.dxf
100.0 x 120.0

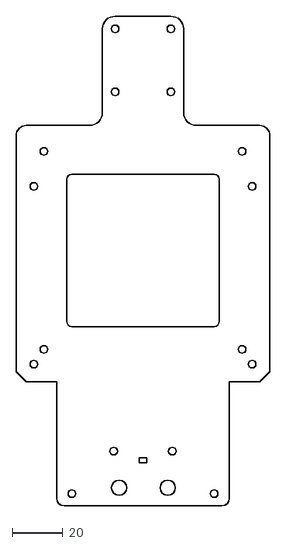
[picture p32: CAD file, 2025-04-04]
models/Vehicle_2D_3D/Vehicle_Chassis_Sizse/Vehicle_Mid-Deck.dxf
100.0 x 192.8

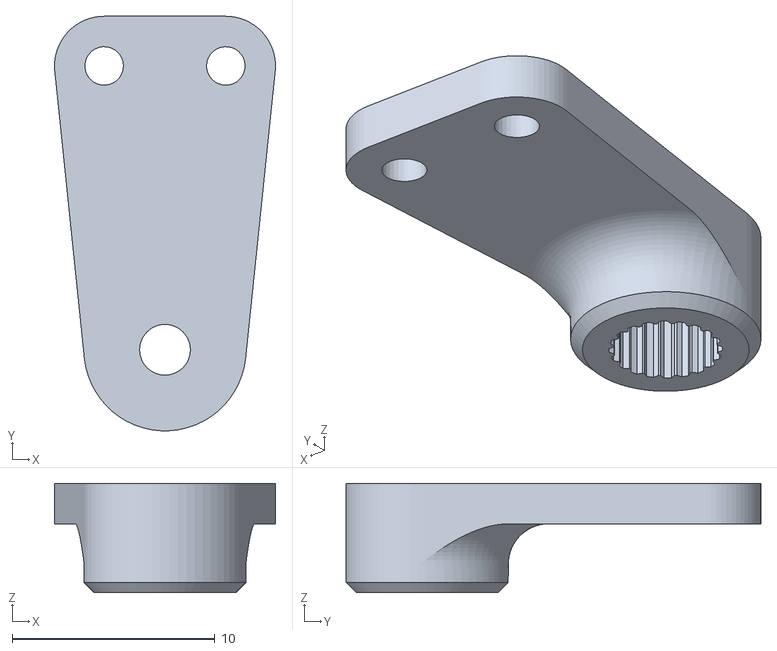
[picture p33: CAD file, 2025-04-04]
models/Vehicle_2D_3D/Vehicle_Chassis_CAD_File/Steering-shaft-holder.stl
10.9 x 20.4 x 5.40

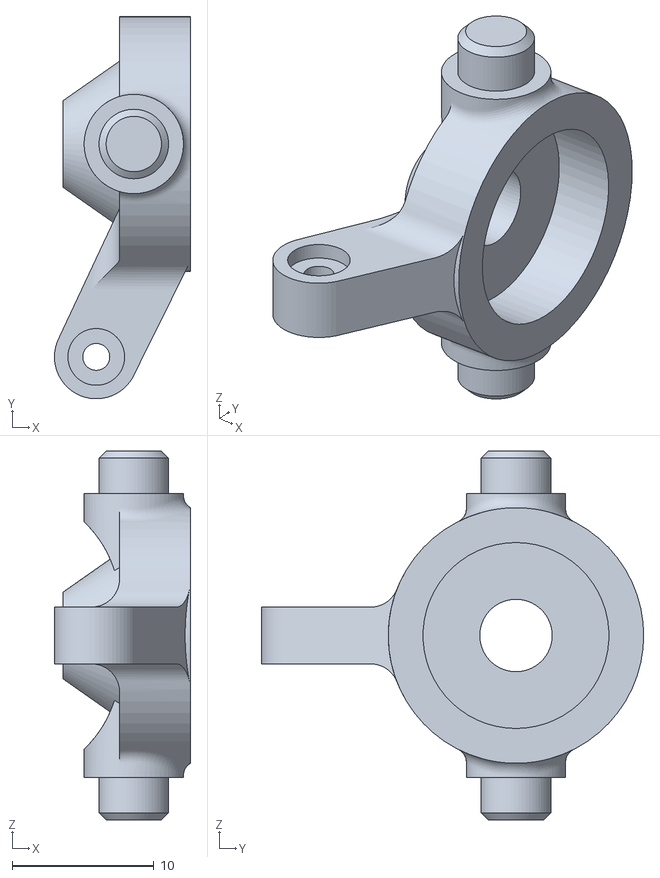
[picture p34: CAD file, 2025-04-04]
models/Vehicle_2D_3D/Vehicle_Chassis_CAD_File/Steering-Knuckle.stl
9.59 x 26.9 x 26.0

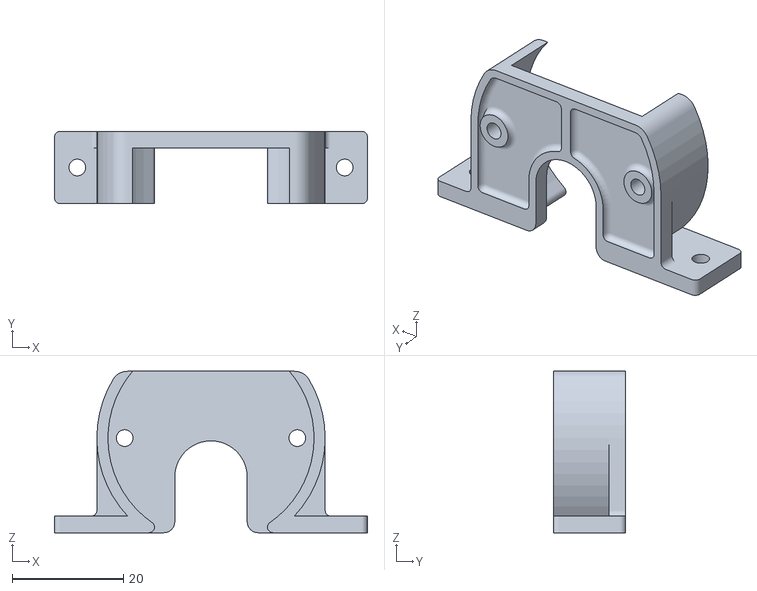
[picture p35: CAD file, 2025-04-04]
models/Vehicle_2D_3D/Vehicle_Chassis_CAD_File/Motor-Holder.stl
56.2 x 13.0 x 29.0

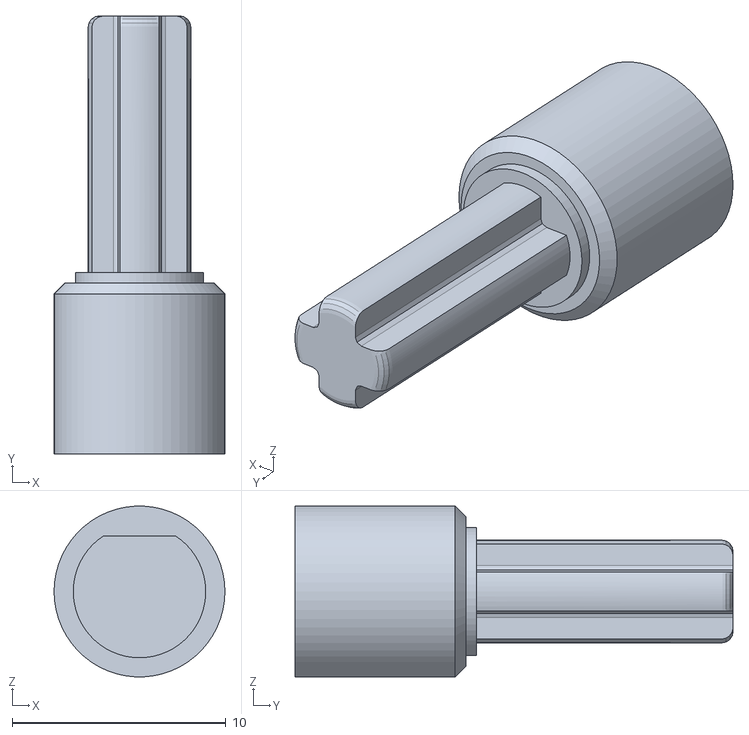
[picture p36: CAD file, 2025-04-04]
models/Vehicle_2D_3D/Vehicle_Chassis_CAD_File/Cross-pin.stl
8.00 x 20.5 x 7.99

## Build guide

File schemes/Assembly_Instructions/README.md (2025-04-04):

<div align="center">logo</div>

## <div align="center">Hardware Assembly Instructions & Wiring diagram</div>
- ### Hardware Configuration of Electronic Equipment
  - The diagram below shows the placement of electronic equipment in the autonomous vehicle.
  
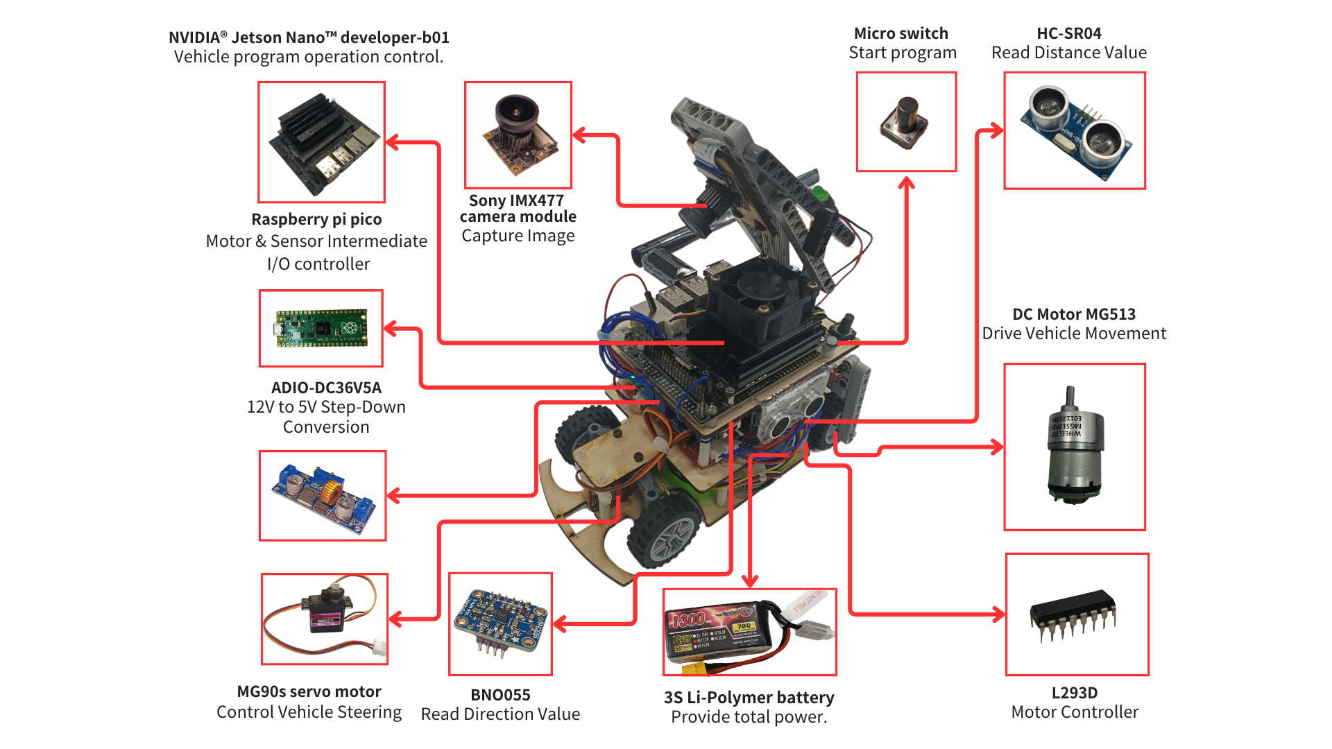
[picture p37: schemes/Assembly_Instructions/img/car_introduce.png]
Components's Position
    

*** 
- ### System Operation Process
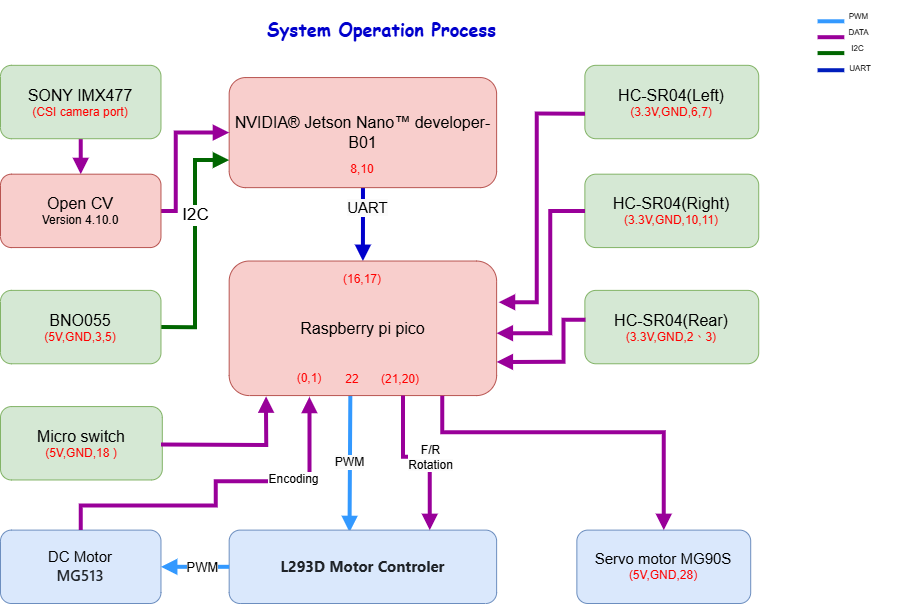
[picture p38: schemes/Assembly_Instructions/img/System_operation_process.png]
System Operation Process
    

- The Nvidia Jetson Nano main controller captures images using a camera module and processes them with OpenCV to detect obstacles and boundary walls. It simultaneously collects directional data from the BNO055 gyroscope orientation sensor via the I2C communication protocol to calculate the travel direction to avoid obstacles and boundary walls. The calculated path data is then transmitted via UART communication to the Raspberry Pi Pico I/O controller for control.
- During parking, the Raspberry Pi Pico, acting as an I/O controller, not only receives data from the Nvidia Jetson Nano main controller but also simultaneously collects distance data from HC-SR04 ultrasonic distance sensors in three directions. Based on this data, it performs calculations to control the movement path for automated parking.
- As an I/O controller, the Raspberry Pi Pico receives vehicle movement control values from the Nvidia Jetson Nano main controller and performs further calculations within the Pico. It then sends the results to the front-wheel servo motor (MG90S) to control the driving direction, thereby completing the obstacle avoidance task.
- At the same time, acting as an I/O controller, the Raspberry Pi Pico processes vehicle movement control values received from the Nvidia Jetson Nano main controller and sends the results to the motor controller (L293D) to control the DC motor’s forward and reverse rotation and speed.

- ### Vehicle Body Structure Display Diagram
<div align="center">
<table>
  <tr>
      <th>Top View of the Overall Apparatus</th>
      <th>Middle Layer Structure Top View</th>
      <th>Top View of Vehicle Chassis</th>
      <th>Bottom View of Vehicle Chassis</th>
  </tr>
  <tr align="center">
     <td>Top View of the Overall Apparatus </td>
     <td>Middle Layer Structure Top View</td>
     <td>Top View of Vehicle Chassis</td>
     <td>Bottom View of Vehicle Chassis</td>
  </tr>
</table>
</div>

- ### Circuit Board 
<div align="center">
<table>
  <tr align="center">
      <th> Circuit Board of Top View </th><th>Circuit Board of Button View</th>
  </tr>
  <tr align="center">
     <td>  </td><td></td>
  </tr>
</table>
</div>

- ### Overview of Important Parts List
  - #### NVIDIA® Jetson Nano™ developer-B01 Controller
    <table border=0 width="100%" >
      <tr>
      <td >

    __Specification:__ 
    - Processor: Quad-core ARM Cortex-A57, 64-bit CPU
    - GPU: 128-core NVIDIA Maxwell GPU
    - Memory: 4GB LPDDR4
    - Connectivity: Gigabit Ethernet, 4×USB 3.0 ports
    - GPIO: 40-pin expansion header, compatible with Raspberry Pi's standard GPIO
    - Dimensions: 100×80×29mm
    - Weight: 140 grams
    <br></br>

    __Uses in Competition:__ 
    - Responsible for receiving image data from the camera module, performing image recognition via OpenCV, and sending the recognition results to the Raspberry Pi Pico for further processing.
    <br></br>
    __Purchase URL:<a href="https://robotkingdom.com.tw/product/rk-nvidia-jetson-nano-developer-b01/" target="_blank">NVIDIA® Jetson Nano™ developer-b01</a>__
    </td>
    <td>
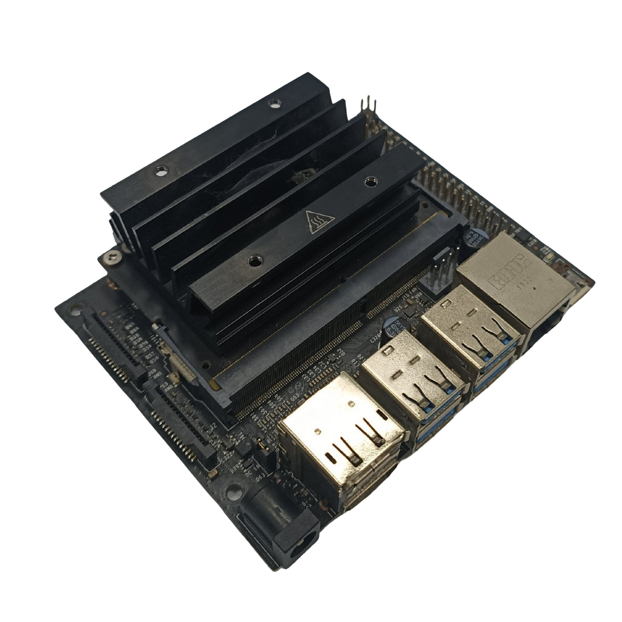
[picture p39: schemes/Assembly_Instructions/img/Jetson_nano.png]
Jetson nano
       
    </td>
    </tr>
    </table>

  - #### MG513 Rear-Drive DC Motor
    <table border=0 width="100%" >
      <tr>
      <td> 

    __Specifications:__  
    - No-load Speed: 366 rpm
    - Reduction Ratio: 1:30
    - Operating Voltage: 6 - 12V
    <br></br>

    __Uses in Competition：__
    - Responsible for receiving control signals from the motor driver controller L293D to adjust the vehicle's forward and reverse movements and control the rear wheel speed.
    <br></br>
    __Purchase URL:[MG513-P30 336RPM DC reduction motor](https://www.amazon.com/-/zh_TW/MG513-12V-%E6%B8%9B%E9%80%9F%E9%BD%92%E8%BC%AA%E9%A6%AC%E9%81%94%E7%B7%A8%E7%A2%BC%E5%99%A8%E4%BB%A3%E7%A2%BC%E9%80%9F%E5%BA%A6%E6%B8%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)__
    </td>
       <td >
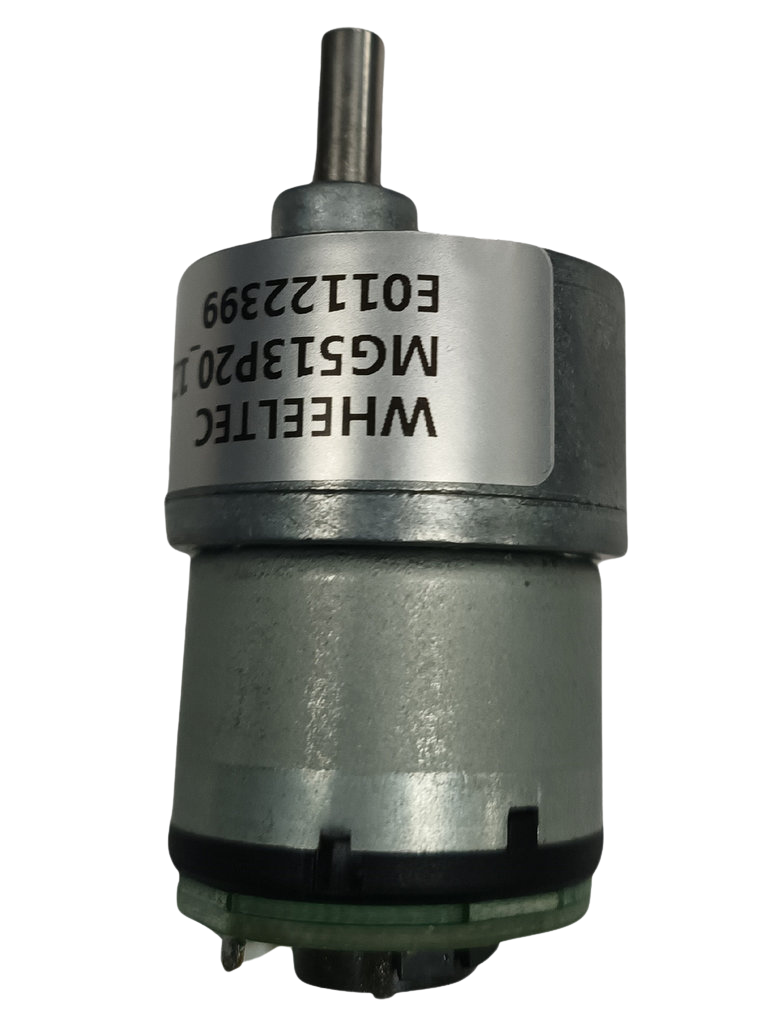
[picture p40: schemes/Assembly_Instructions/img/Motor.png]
MG513-P30
       
      </td>
      </tr>
    </table>

  - ### MG90S Front Steering Mechanism by Servo Motor
      <table border=0 width="100%" >
      <tr>
      <td> 

    __Specifications:__
    - Controllable Rotation Angle: 0-180°  
    - Maximum Torque: 2.0 kg/cm (at 4.8V)  
    - Fastest Rotation Speed: 0.11 seconds (at 4.8V)  
    - Operating Voltage: 4.8V - 7.2V  
    <br></br>

    __Uses in Competition：__
    - Responsible for receiving control values from the Raspberry Pi Pico to adjust the front wheel steering angle, enabling precise steering during driving.
    <br></br>
    __Purchase URL:<a href="https://www.amazon.com/-/zh_TW/dp/B0BFQLNDPM" target="_blank">MG90s servo motor</a>__
    </td>
       <td >
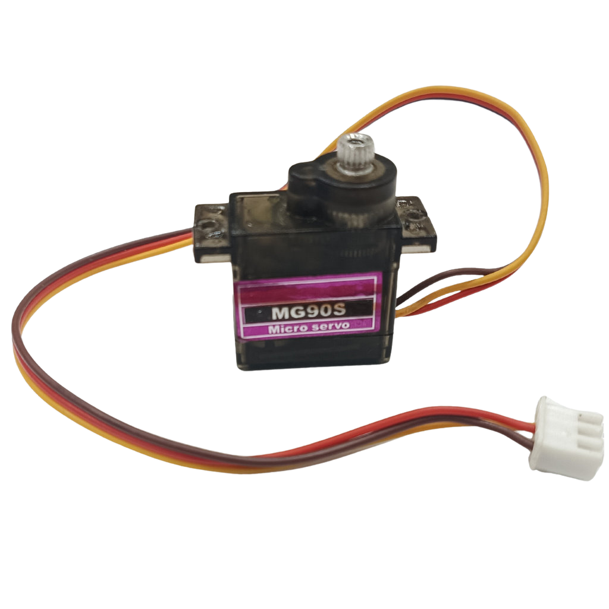
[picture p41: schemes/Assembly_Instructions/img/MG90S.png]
MG90S servo motor
      
       </td>
      </tr>
    </table>

  - #### Dual H-bridge DC motor driver IC - L293D

    <table border=0 width="100%" >
      <tr>
      <td>  

    __Specifications:__ 
    - 293D is a dual H-bridge DC motor driver IC that can be used to control two DC motors.
    - Wide operating voltage range: 4.5V to 36V.
    - Output current: 600 mA (continuous) and 1.2 A (peak) per channel.
    - Output voltage range: 3 V to 36 V.
    <br></br>

    __Uses in Competition：__  
    - Primarily responsible for driving the MG513 geared DC motor to control the vehicle’s forward and reverse movement, as well as the motor’s speed.
    <br></br>
    __Purchase URL:<a href="https://atceiling.blogspot.com/2019/08/arduino54l293d.html" target="_blank">L293D</a>__
    </td>
      <td>
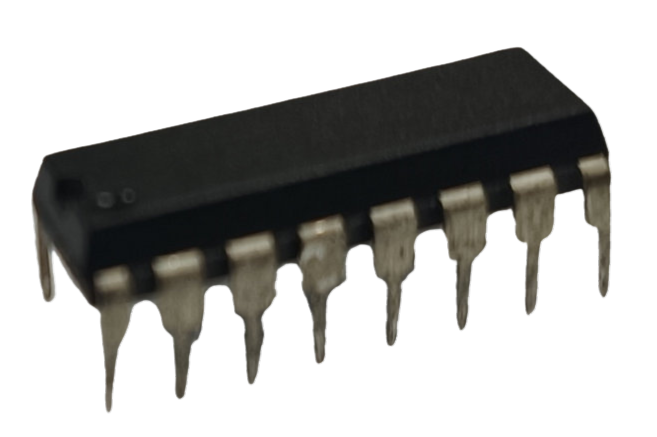
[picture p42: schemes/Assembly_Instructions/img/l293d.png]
L293d motor controler
      
      </td>
      </tr>
    </table>

  - #### Li-Polymer 3S Battery
    <table border=0 width="100%" >
      <tr>
      <td> 

    __Specifications:__
    - Maximum Current: 45.5A  
    - Net Weight: Approximately 107g  
    - Rated Voltage: 11.1V
    <br></br>

    __Uses in Competition：__  
    - Supply power to the vehicle for use.  
    <br></br>
    __Purchase URL:<a href="https://shopee.tw/product/17393576/2036942264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" target="_blank">Li-Polymer 3S Battery</a>__
    </td>
    <td>
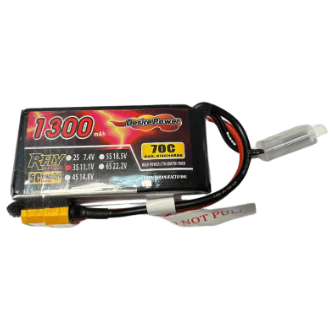
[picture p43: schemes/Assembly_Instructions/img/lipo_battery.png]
Li-Polymer 3S Battery
      
    </td>
    </tr>
    </table>

  - #### Micro switch (TACK-SW)

    <table border=0 width=100% >
      <tr>
      <td>

    __Specifications:__ 
    - Operating Voltage: 3.3V - 5.0V  
    - Number of Pins: 3  
    - Output Signal: Digital  
    <br></br>

    __Uses in Competition：__
    - Control the vehicle's start and drive switch.
    <br></br>
    __Purchase URL:<a href="https://www.amazon.com/-/zh_TW/PLKXSEYUJ/dp/B0D4HZFM6S" target="_blank">Micro switch</a>__
    </td>
      <td>
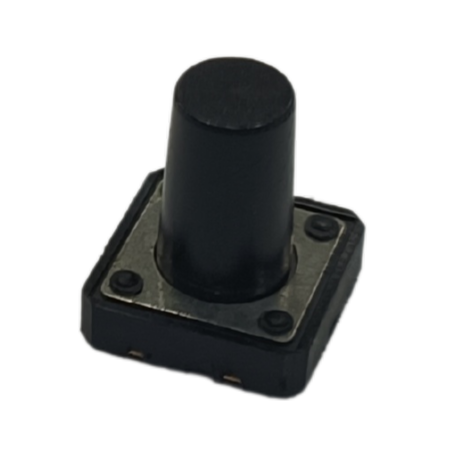
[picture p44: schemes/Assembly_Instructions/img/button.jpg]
Button(TACK-SW)
       
      </td>
      </tr>
    </table>

  - #### High Current 5A Constant Voltage Constant Current Buck Power Supply Module ADIO-DC36V5A

    <table border=0 width=100% >
      <tr>
      <td> 

    __Specifications:__ 
    - Input Voltage Range: 4 - 38V
    - Output Voltage Range: 1.25 - 36V, continuously adjustable
    - Output Current Range: Adjustable, maximum of 5A
    <br></br>

    __Uses in Competition：__  
    - Primarily responsible for stepping down the battery voltage from 11.1V to 5V to provide various stable voltages needed for vehicle operation.
    <br></br>
    __Purchase URL:<a href="https://shop.cpu.com.tw/product/57434/info/" target="_blank">ADIO-DC36V5A</a>__
    </td>
      <td>
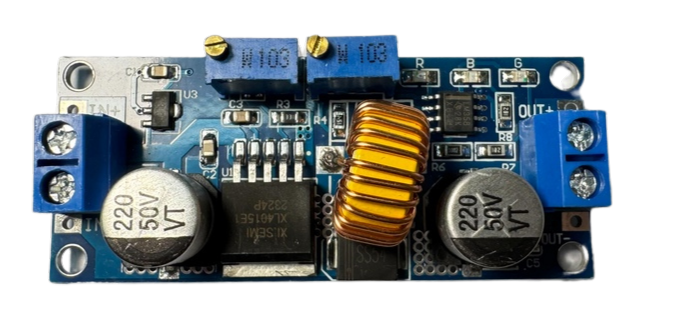
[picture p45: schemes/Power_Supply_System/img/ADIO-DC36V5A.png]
ADIO-DC36V5A
       
      </td>
      </tr>
    </table>

  - #### SONY IMX477 Camera Module
    <table border=0 width="100%" >
      <tr>
      <td>

    __Specifications:__
    - Viewing Angle: 160 degrees
    - pixels: 4056 x 3040
    - Maximum aperture: F2.0
    - Focal length: 7.9mm
    - Interface: CSI (Camera Serial Interface)
    - Operating Voltag：3.3V
    <br></br>

    __Uses in Competition：__  
    - Responsible for capturing images and transmitting them to the Jetson Nano for image recognition to detect the presence of obstacles or boundary walls.
    <br></br>
    __Purchase URL:<a href="https://shopee.tw/%E7%8F%BE%E8%B2%A8-SONY-IMX477-%E6%94%9D%E5%BD%B1%E9%8F%A1%E9%A0%AD%E6%A8%A1%E7%B5%84-1230%E8%90%AC%E5%83%8F%E7%B4%A0-160%C2%B0%E5%BB%A3%E8%A7%92-%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" target="_blank">SONY IMX477</a>__
    </td>
       <td >
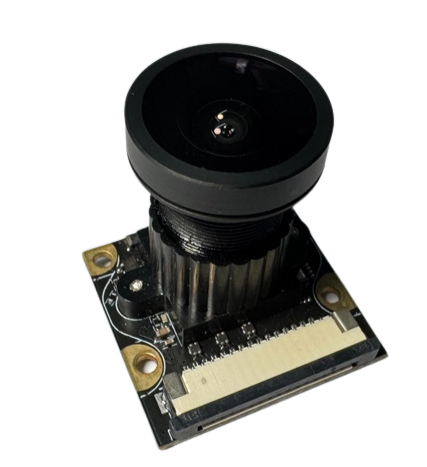
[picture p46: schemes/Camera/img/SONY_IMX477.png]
SONY IMX477 Camera Module
        
       </td>
      </tr>
    </table>

  - #### BNO055 Gyroscope orientation sensor
    <table border=0 width="100%" >
      <tr>
      <td> 

    __Specifications:__
    - 9-Axis Sensing: Includes accelerometer, gyroscope, and magnetometer for motion and orientation detection
    - Operating Voltage: 3.6V - 5V
    - Interface: Supports both I²C and UART, making it compatible with various devices
    - Orientation Data: Provides direct angle data for accurate positioning
    <br></br>

    __Uses in Competition：__  
    - Responsible for detecting the vehicle's current orientation values, which are provided to the  Jetson Nano controller for processing and decision-making.
    <br></br>
    __Purchase URL:<a href="https://www.remisys.com.tw/product-page/bno055-absolute-orientation-sensor" target="_blank">BNO055</a>__
    </td>
       <td >
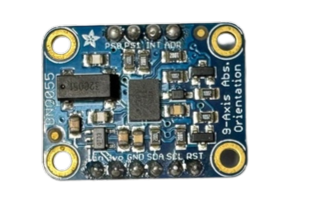
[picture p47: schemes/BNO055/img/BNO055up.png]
SBNO055 Gyroscope orientation sensor
        
       </td>
      </tr>
    </table>

  - #### HC-SR04 ultrasonic distance sensor
    <table border=0 width="100%" >
      <tr>
      <td> 

    __Specifications:__
    - Measuring Range: 2 cm to 400 cm, capable of detecting objects within a distance of 2 cm to 4 meters.
    - Measurement Accuracy: Approximately 3 mm, with a margin of error around ±3 mm.
    - Operating Voltage: 5V, powered by direct current.
    - Ultrasonic Frequency: 40kHz, measuring distance by emitting a 40kHz ultrasonic signal.
    - Transmission Interface: Includes Trig and Echo pins, where Trig sends out the ultrasonic signal and Echo receives the reflected signal to calculate the distance.
    <br></br>

    __Uses in Competition：__  
    - Primarily responsible for collecting distance data from HC-SR04 ultrasonic distance sensors in three directions and providing it to the Raspberry Pi Pico controller for calculations to control the vehicle's direction.
    <br></br>
    __Purchase URL:<a href="https://robotkingdom.com.tw/product/hc-sr04p-ultrasonic-ranger/" target="_blank">HC-SR04</a>__
    </td>
       <td >
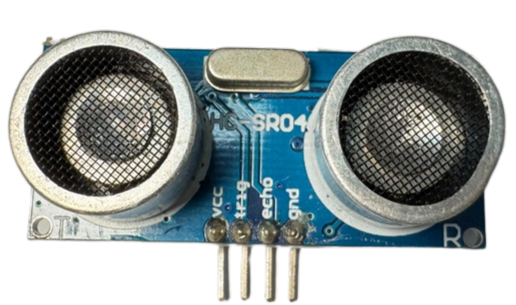
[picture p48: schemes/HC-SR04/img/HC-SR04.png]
HC-SR04 ultrasonic distance sensor
        
       </td>
      </tr>
    </table>

# <div align="center">HOME[Return Home](../../)</div>

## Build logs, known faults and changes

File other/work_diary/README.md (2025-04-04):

<div align="center">logo</div>

# <div align="center">Work Diary</div>

The following is a development record of the self-driving car model design and task-solving, covering mechanical design and manufacturing, circuit design and implementation, electronic device selection, programming and testing, and the overall problem-solving process.
## 2024/03/04 ~ 2024/03/10  

**Member:** HU,SIAN-YI、LAI,MENG-CHENG、HUANG,KE-FU

**Content:**  

My partner, "HU, SIAN-YI," has participated in the Future Engineering Competition multiple times over the past few years, accumulating substantial experience in mechanical design and programming. However, since the competition themes change or introduce new challenges each year, we decided after discussion to use last year's models from our seniors and the design of last year's world champion team as references for this year's competition model.

<div align="center">
<table>
<tr align="center">
<th colspan="2">Last year's senior's model</th>
</tr>
<tr align="center">
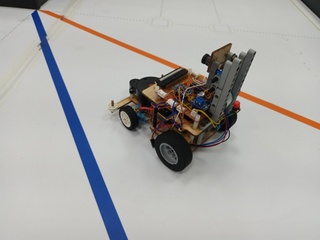
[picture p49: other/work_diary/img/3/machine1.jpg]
<td> </td>
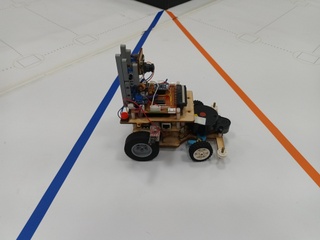
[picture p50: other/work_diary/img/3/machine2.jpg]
<td></td>
</tr>
<tr align="center">
<th colspan="2">Refer to the seniors GitHub reports(參考學長姐們的Github報告)</th>
</tr>
<tr align="center">
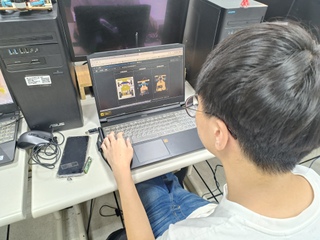
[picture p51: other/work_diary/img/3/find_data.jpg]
data
<td> </td>
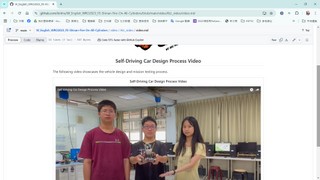
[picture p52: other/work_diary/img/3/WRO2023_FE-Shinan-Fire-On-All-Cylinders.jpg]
<td></td>
</tr>
</table>
</div>

## 2024/03/11 ~ 2024/03/17

**Member:** HU,SIAN-YI、LAI,MENG-CHENG、HUANG,KE-FU

**Content:**

- In order to smoothly advance the competition activities while balancing academic work, we have developed a work schedule to ensure the timely completion of each task, as detailed in the diagram below.
- We first familiarized ourselves with the model designed by our seniors and attempted to get the vehicle running smoothly. However, we found that there were still some technical details we were unfamiliar with, such as the calibration and use of LiDAR sensors, installation of the Raspberry Pi controller, and programming, which led to the self-driving car not yet operating successfully.

  **Completion Time Planning Table for Each Stage of the Competition Activities (Gantt Chart)**

<div align="center" >
  gantt
</div>

### Writing the program and adjusting the machine

<div align="center" >
<table >
<tr align="center">
<th>Writing the program</th>
<th>Adjusting the machine</th>
<tr align="center">
<td>
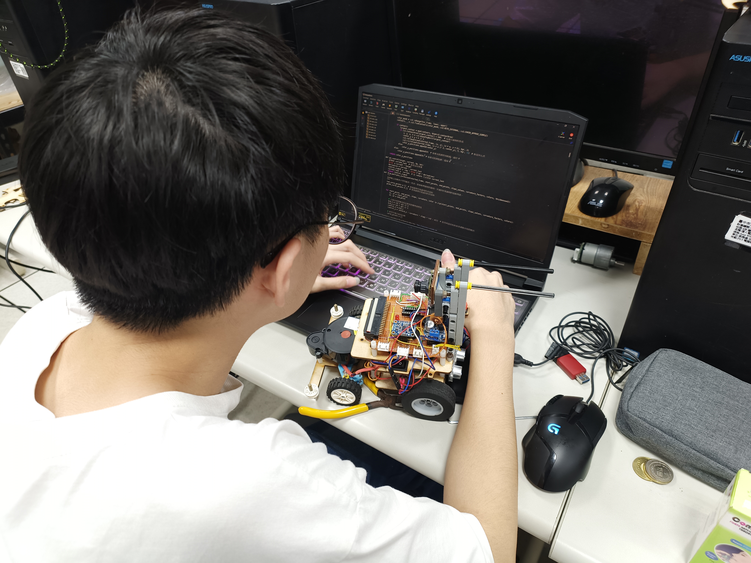
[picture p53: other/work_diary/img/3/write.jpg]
write
</td>
<td>
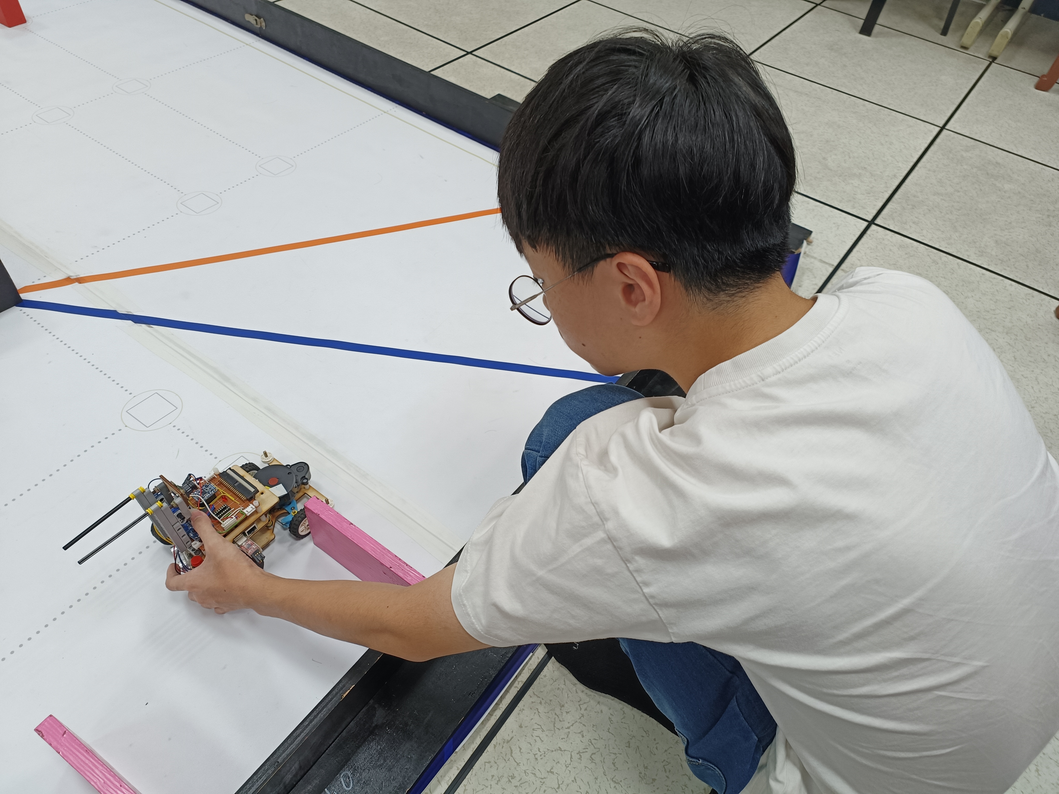
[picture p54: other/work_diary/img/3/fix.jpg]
fix
</td>
</tr>
</table>
</div>

## 2024/03/18 ~ 2024/03/24

**Member:** HU,SIAN-YI、LAI,MENG-CHENG、HUANG,KE-FU  

**Content:**  

#### Raspberry pi 4

- We began writing the code for the qualifying round, and with the assistance of our seniors, our progress accelerated significantly, allowing us to successfully complete the coding for the qualifying round.
- We started writing the obstacle avoidance program for the task competition and practiced techniques for adjusting the camera. Since the accuracy of the camera may shift after a few days, which can easily lead to misdetections, we placed particular emphasis on practicing adjustments in this area.

#### Practice situation

<div align="center" >
<table >
<tr align="center">
<th>Adjust the camera</th>
<th>Write the program</th>
<tr align="center">
<td>
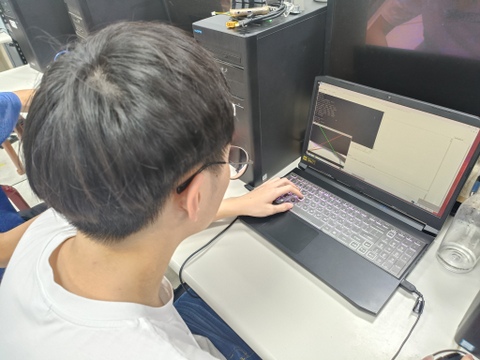
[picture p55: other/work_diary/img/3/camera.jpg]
</td>
<td>
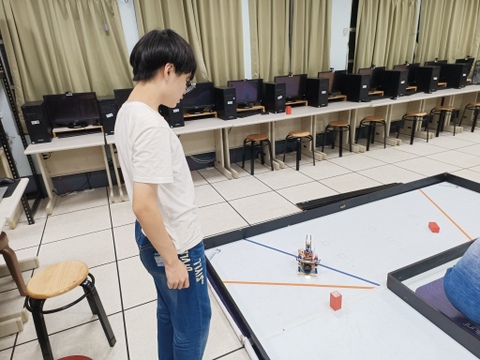
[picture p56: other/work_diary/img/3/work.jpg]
</td>
</tr>
</table>
</div>

## 2024/03/25 ~ 2024/03/31  

**Member:** HU,SIAN-YI、LAI,MENG-CHENG、HUANG,KE-FU

**Content:** 

- Since the model designed by our seniors used radar, we discovered during testing that the radar data was unstable, and we also faced challenges with camera control. Even after camera calibration, errors still existed. Therefore, we plan to redesign a new machine. To be prudent, we decided to continue developing and refining the Raspberry Pi system while designing the new machine, to ensure that we still have a reliable self-driving car available for the competition.
- After discovering issues with the Raspberry Pi system, we referred to the self-driving car used by the previous competition's champion, which utilized the Jetson Nano as the main controller. This significantly improved the efficiency of visual recognition and reduced reliance on less stable sensors such as LiDAR and color sensors. Therefore, we plan to use the Jetson Nano as the main controller to design a brand-new self-driving car.
- Currently, the self-driving car using the Raspberry Pi system is still being revised by MENG-CHENG, while the development of the new self-driving car is being designed and built by the experienced partners SIAN-YI and KE-FU.

  <div align=center>
  <table>
  <tr>
  <th rowspan="2" width=300>Photo</th>
  <th>Nvidia Jetson Nano</th>
  <th>Raspberry Pi 4B</th>
  </tr><tr>
  <td><div align=center></td>
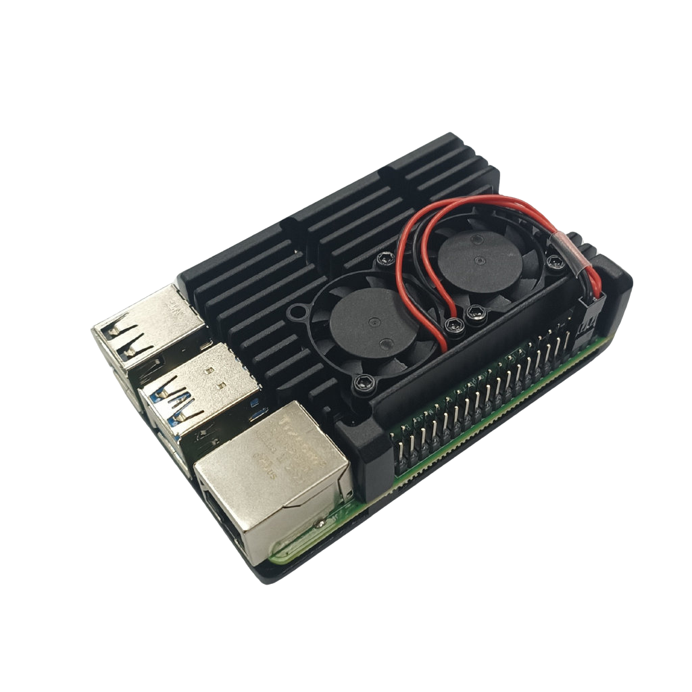
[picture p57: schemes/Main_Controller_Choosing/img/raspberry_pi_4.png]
  <td><div align=center></td>
  </tr><tr>
  <th>Number of Pins</th>
  <td>40P</td>
  <td>40P</td>
  </tr><tr>
  <th>CPU</th>
  <td>Quad-core ARM® Cortex®-A57 MPCore</td>
  <td>1.5GHz 64-bit Quad-core ARM Cortex-A72 CPU</td>
  </tr><tr>
  <th>GPU</th>
  <td>NVIDIA Maxwell™ architecture with 128 NVIDIA CUDA®  cores</td>
  <td>Broadcom VideoCore VI<br> H.265 (4kp60 decode)<br> H264 (1080p60 decode, 1080p30 encode) OpenGL ES 3.1<br> Vulkan 1.0</td>
  </tr><tr>
  <th>Storage Spac</th>
  <td>4 GB 64-bit LPDDR4</td>
  <td>8GB LPDDR4-3200 SDRAM</td>
  </tr><tr>
  <th>Built-in Bluetooth and Wireless WiFi Connectivity</th>
  <td>Requires external Bluetooth and wireless WiFi connectivity</td>
  <td>Built-in</td>
  </tr><tr>
  <th>Gflops</th>
  <td>472</td>
  <td>13.5</td>
  </tr><tr>
  <th>Price</th>
  <td>Expensive</td>
  <td>Cheap</td>  
  </tr>
  </table>
  </div>

- **Supplementary Information**

  **Aspects of deep learning acceleration**
   - Jetson Nano: Supports NVIDIA CUDA and cuDNN, which can accelerate deep learning workloads. For tasks like image classification and object detection, the GPU in Jetson Nano significantly enhances processing speed.
   - Raspberry Pi 4: Lacks a dedicated GPU and deep learning acceleration capabilities; image recognition tasks rely entirely on CPU processing, which is far less efficient than the GPU acceleration of Jetson Nano.

## 2024/04/01 ~ 2024/04/07

**Member:** HU,SIAN-YI、LAI,MENG-CHENG、HUANG,KE-FU

**Content:**

- We decided to conduct tests separately, with one team continuing to test and refine the Raspberry Pi 4B, while the other began studying the Nvidia Jetson Nano.
- We started researching the Jetson Nano and began setting up its system environment.
- We documented the system installation process in <a href="../../src/System_Platform_Software/README.md">3-1 Software Platform Construction</a>.
<div align="center" >
<table >
<tr align="center">
<th>Jetson nano environment setup</th>
<tr align="center">
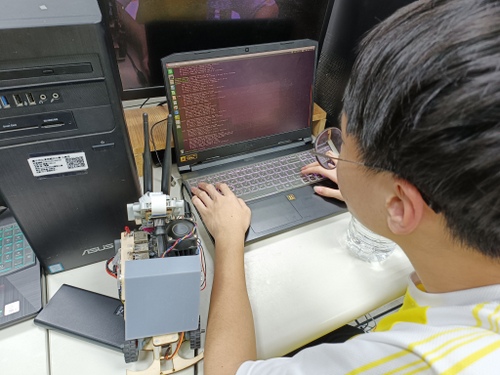
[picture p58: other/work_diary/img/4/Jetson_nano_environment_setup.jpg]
setup
<td></td>
</tr>
</table>
</div>

## 2024/04/08 ~ 2024/04/14

**Member:** HU,SIAN-YI、LAI,MENG-CHENG、HUANG,KE-FU  

**Content:**  
- After reviewing the I/O control aspects of the Jetson Nano, we identified the following drawbacks:

  - Processing Limitations: While the Jetson Nano excels in handling AI and machine learning tasks, its CPU is relatively limited and may face performance bottlenecks when performing extensive I/O control tasks, especially when handling complex computations and I/O operations simultaneously.
  - GPIO Latency: Compared to dedicated microcontrollers (such as Arduino, ESP32, etc.), the Jetson Nano may have higher latency when using Python or other high-level languages for GPIO control, which affects applications requiring high real-time performance.
  - Limited Hardware Interfaces: The number of GPIO pins provided by the Jetson Nano is relatively limited. If a large number of I/O interfaces are needed, expansion boards may be required, increasing development costs and complexity.
  - Software Driver Support Issues: Certain I/O devices may not be fully supported by the Jetson Nano’s drivers or may require additional development and debugging to communicate properly with specific peripherals.
  - Voltage Incompatibility: The GPIO on the Jetson Nano typically operates at 3.3V, which can be incompatible with some 5V I/O devices, necessitating the use of voltage converters for level matching.
- Due to the Jetson Nano's inability to handle too many sensors simultaneously, we need to use additional microcontrollers as extension boards to facilitate more efficient signal communication between the sensors and the Jetson Nano main controller.
- The Raspberry Pi Pico and ESP32 WiFi, two commonly used microcontroller boards in Taiwan, are well-equipped to handle sensor data and motor control tasks.
- To facilitate the selection of the optimal intermediate I/O controller for our autonomous vehicle, we will conduct a comparative analysis of the specifications and costs of these two options.
- The Raspberry Pi Pico  offers simplicity, low power consumption, and affordability, making it ideal for applications with low wireless demands. It also aligns well with the requirements of this competition. Therefore, we have chosen the Raspberry Pi Pico as a relay management controller for the Nvidia Jetson Nano, responsible for managing motors and sensors.

<div align=center>
<table>
<tr>
<th rowspan="2" width=300>Photo</th>
<th>Raspberry Pi Pico</th>
<th>Esp32 wifi</th>
</tr><tr>
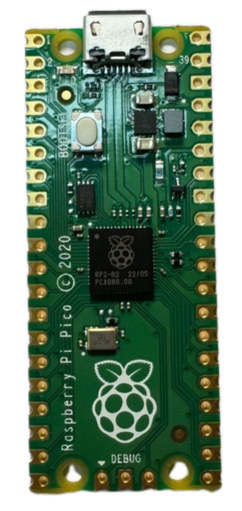
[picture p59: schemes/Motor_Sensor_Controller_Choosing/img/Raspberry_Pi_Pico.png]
<td><div align=center></td>
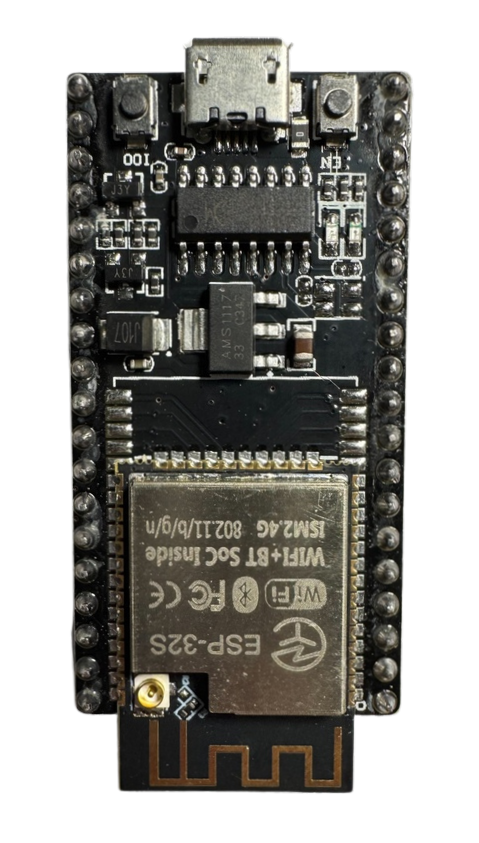
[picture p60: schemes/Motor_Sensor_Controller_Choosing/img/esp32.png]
<td><div align=center></td>
</tr><tr>
<th>CPU</th>
<td>Dual-core ARM Cortex-M0+ @ 133 MHz</td>
<td>Dual-core Xtensa LX6 @ 160/240 MHz</td>
</tr>
<tr>
<th>RAM</th>
<td>264 KB SRAM</td>
<td>520 KB SRAM</td>
</tr>
<tr>
<th>WIFI</th>
<td>None</td>
<td>Wi-Fi 802.11b/g/n (2.4 GHz), Bluetooth (v4.2)</td>
</tr>
<tr>
<th>Storage</th>
<td>2 MB Flash</td>
<td>Supports external Flash (typically 4 MB to 16 MB)</td>
</tr>
<tr>
<th>GPIO</th>
<td>26 GPIO pins</td>
<td>34 GPIO pins</td>
</tr>
<tr>
<th>ADC</th>
<td>3-channel ADC (12-bit).</td>
<td>18-channel ADC (12-bit).</td>
</tr>
<tr>
<th>PWM</th>
<td>Configurable PWM output.</td>
<td>Supports multi-channel PWM</td>
</tr>
<tr>
<th>Data transmission interface</th>
<td>I2C, SPI, UART</td>
<td>I2C, SPI, UART, CAN, I2S</td>
</tr>
<tr>
<th>Voltage input</th>
<td>1.8V - 5.5V</td>
<td>2.2V - 3.6V</td>
</tr>
<tr>
<th>size</th>
<td>51 x 21 mm</td>
<td>18 x 25 mm</td>
</tr>
<tr>
<th>Price</th>
<td>cheap</td>
<td>Relatively expensive</td>
</tr>
<tr>
<th>Development environment</th>
<td>MicroPython、C/C++</td>
<td>Arduino IDE、MicroPython、ESP-IDF</td>
</tr>
</tbody>
</table>
</div>

## 2024/04/15 ~ 2024/04/21  

**Member:** HU,SIAN-YI、LAI,MENG-CHENG、HUANG,KE-FU  

**Content:**  

#### Raspberry pi 4

- We began adjusting the Raspberry Pi program for the final round of the obstacle-avoidance task. The first step is to fine-tune the P value for obstacle avoidance to optimize the control response. Once the machine operates stably, we will further adjust the lines on the camera display, fine-tuning the vehicle's response to the x-axis of the blocks. This will enhance the overall obstacle avoidance performance. These steps will progressively improve the system's stability and accuracy, ensuring the successful completion of the obstacle-avoidance task.

#### Jetson nano

- Since we are using the Jetson Nano as the main controller and retaining the Ackermann mechanism components from the Raspberry Pi version of the self-driving car, we need to design a new vehicle chassis to meet our requirements. We used Onshape to draw the chassis sketch and attempted to cut the wooden board using a laser cutter, initiating the assembly process.
- For detailed information about the chassis construction process, please refer to <a href="../../models/Vehicle_2D_3D/README.md"> 1-1 Vehicle 2D/3D Models in CAD</a>.
- We ordered various sensor components online to be used with the Jetson Nano (such as a gyroscope and camera module), a 12V to 5V buck converter, motor driver board, motors, and a microcontroller board (Raspberry Pi Pico) to support the design and development of the vehicle.

<div align="center" width=100%>
<table >
<tr align="center">
  <th>Program adjustments</th>
  <th>board</th>
  <th>onshape <a href="https://www.onshape.com/en/" target="_blank">website</a></th>
  </tr>
<tr align="center">
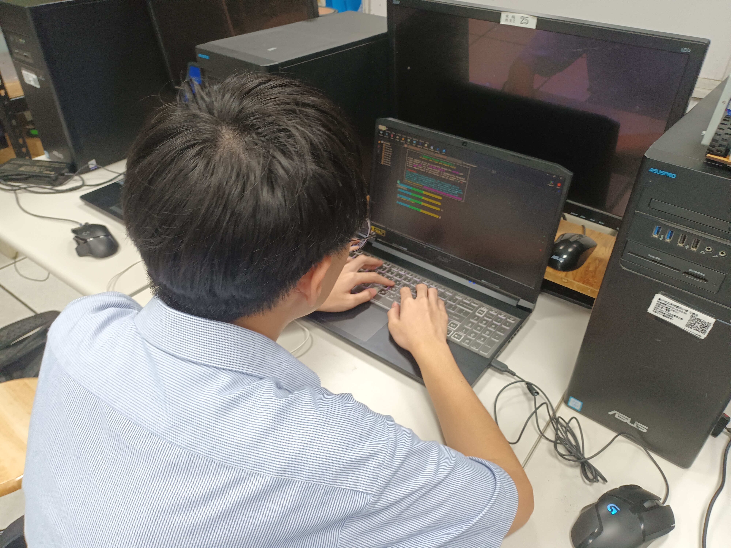
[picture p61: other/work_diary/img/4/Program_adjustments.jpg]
  <td>  </td>
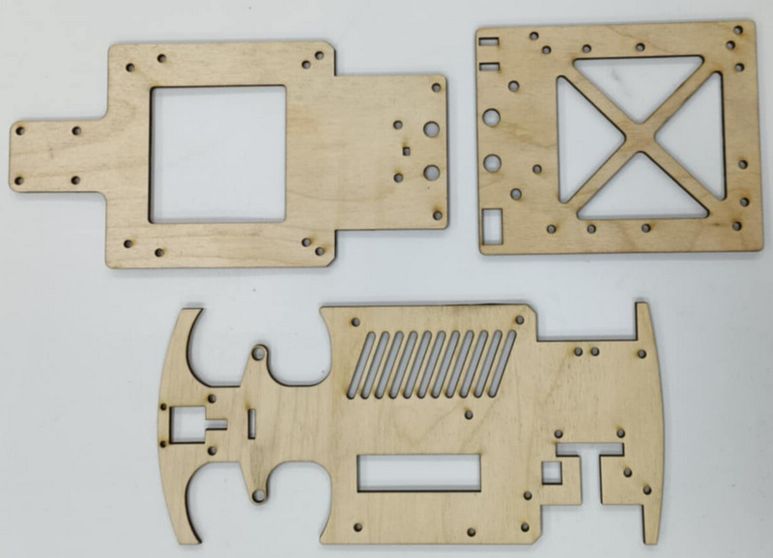
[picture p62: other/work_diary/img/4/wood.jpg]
wood
  <td>  </td>
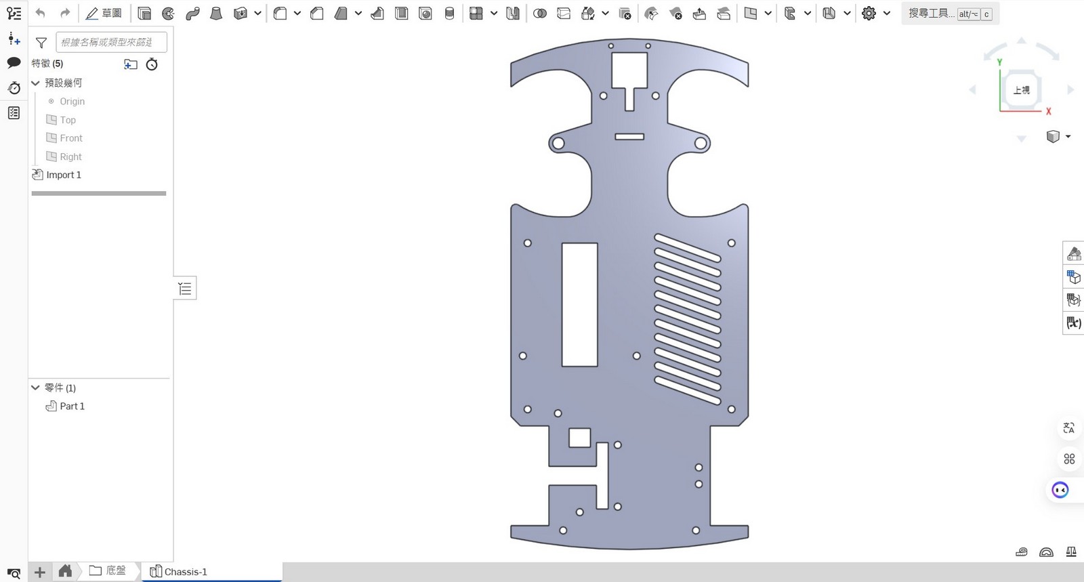
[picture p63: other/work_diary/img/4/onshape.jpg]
onshape
  <td>
  </td>
  </tr>
</table>
</div>
 
## 2024/04/22 ~ 2024/04/28 

**Member:** HU,SIAN-YI、LAI,MENG-CHENG、HUANG,KE-FU  
**Content:**  

#### Raspberry pi 4

- This week, we have nearly finished adjusting the Raspberry Pi's obstacle-avoidance program. However, we noticed that during turns, the machine would often collide with nearby blocks. After identifying the issue, we first checked whether other blocks were in the line of sight, but no blocks were detected. Despite this, the problem persisted, so we shifted our focus to the timing of the turns. Eventually, we decided to have the machine travel a little further before making a turn. This adjustment successfully resolved the issue and prevented the machine from colliding with the nearby blocks.

<div align="center" width=100%>
<table >
<tr align="center">
  <th>Colliding with blocks</th>
  </tr>
<tr align="center">
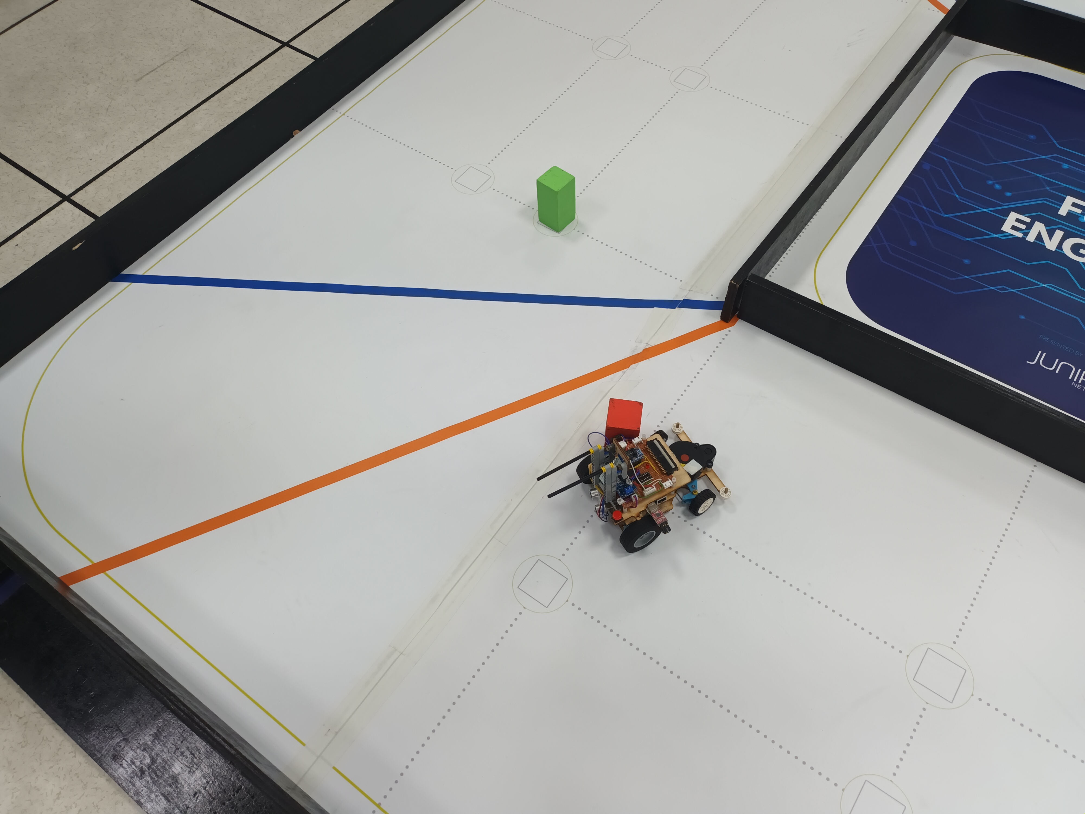
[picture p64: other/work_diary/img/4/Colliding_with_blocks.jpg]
  <td>  </td>
  </td>
  </tr>
</table>
</div>

#### Jetson nano

- We purchased DC motors with model numbers JGB37-520, MG513-P20, and MG513-P30 online to be used as the vehicle's rear-drive motors, and conducted actual tests on their rotational speed and torque.
- Through experiments, we learned that the speed and torque of the MG513-P30 (366 rpm/1 kg.cm) are more suitable for use as the rear-drive DC motor for this competition vehicle.
- When testing the motor operation, simply providing positive and negative terminals cannot effectively control the DC motor's movement or adjust its speed. Therefore, a motor controller is required to implement speed regulation. We have two options: the L293D chip, the L298N module, and the TB6612FNG. To reduce weight, we chose the smaller L293D chip. Its compact size allows us to install more sensors, save space, reduce weight, and enhance the robot's maneuverability.

### Rear-Drive DC Motor

<div align="center">
<table>
<tr ><th colspan="4">DC Motor Comparison</th></tr>
<tr align="center">
<th rowspan="2" >Model</th>
<th >MG513-P20</th>
<th >MG513-P30</th>
<th >JGB37-520</th>
</tr>
<tr align="center">
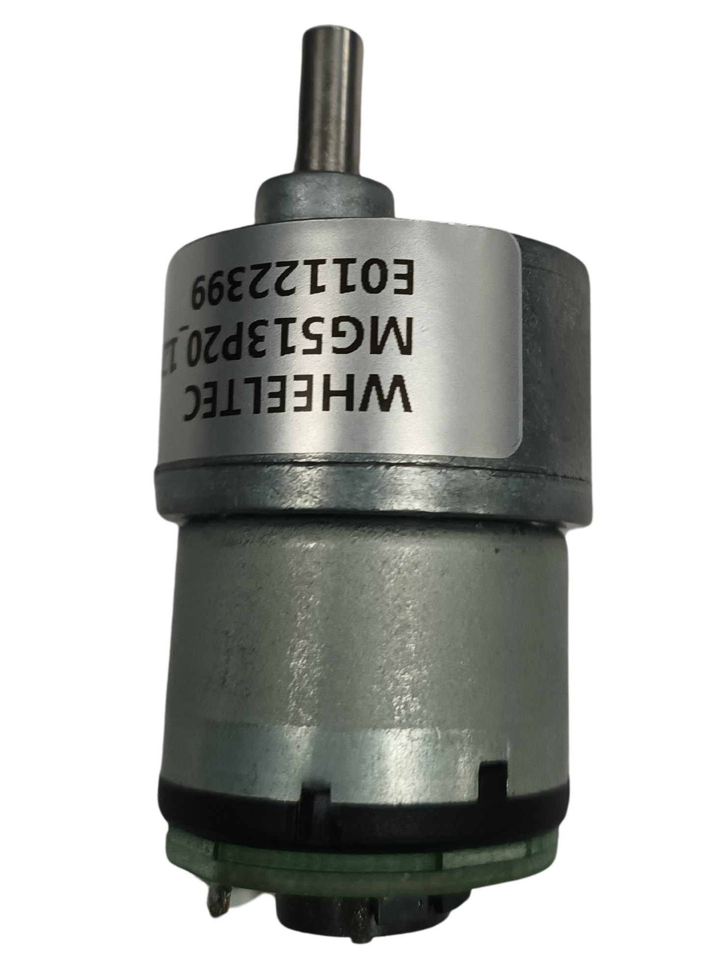
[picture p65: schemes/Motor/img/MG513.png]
MG513
<td colspan="2"></td>
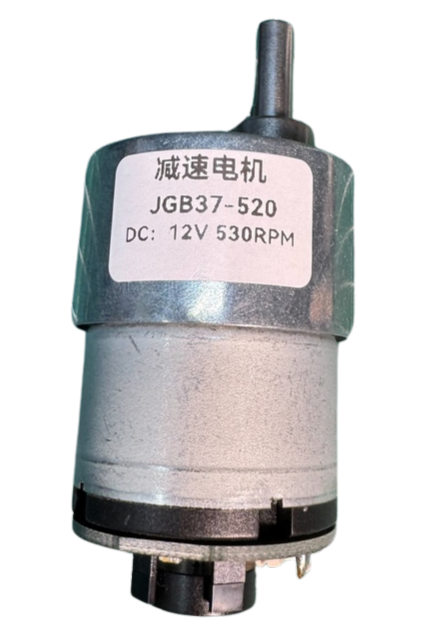
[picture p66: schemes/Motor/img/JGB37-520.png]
JGA25-370_620RPM
<td ></td>
</tr>
<tr align="center">
<td >Reduction ratio</td> 
<td >20</td>
<td >30</td>
<td >19</td>
</tr>
<tr align="center">
<td >Speed</td> 
<td >549rpm</td>
<td >366rpm</td>
<td >530rpm</td>
</tr>
<tr align="center">
<td>Torque</td>
<td>0.66kg.cm</td>
<td>1kg.cm</td>
<td>2.2kg.cm</td>
</tr>
</table>
</div>

### Motor Drive Controller

<div align="center">
<table>
<tr><th colspan="4">Motor Control Comparison</th></tr>
<tr align="center" >
<th rowspan="2">Model</th>
<th>L293D</th>
<th>L298N</th>
<th>TB6612FNG</th>
</tr>
<tr align="center">
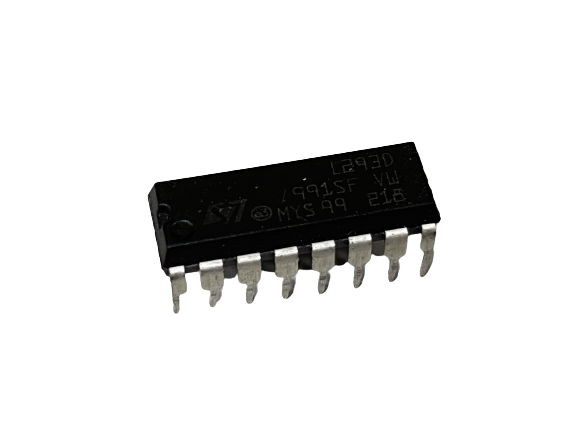
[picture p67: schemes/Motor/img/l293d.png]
l293d
<td> </td>
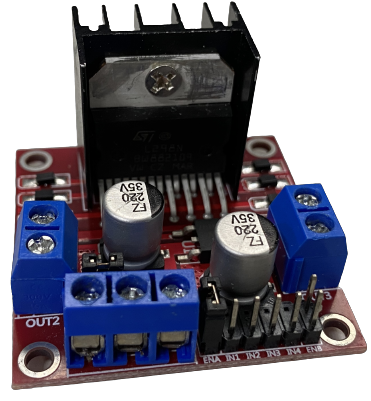
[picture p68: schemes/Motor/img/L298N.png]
l298n
<td ></td>
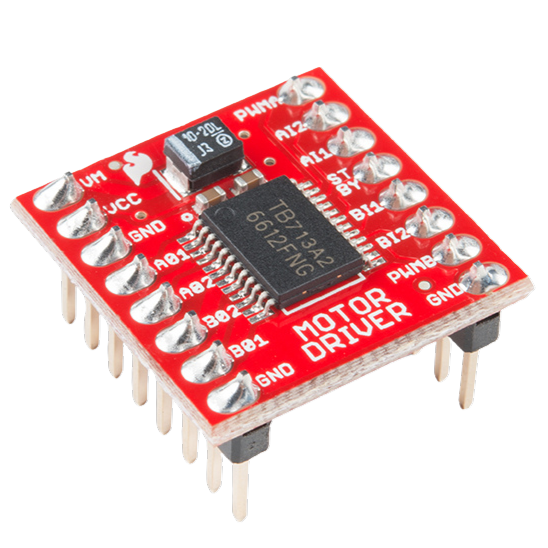
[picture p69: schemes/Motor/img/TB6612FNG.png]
TB6612FNG
<td ></td>
</tr>
<tr align="center">
<td>Occupied Area(mm)</td>
<td>29.5x8</td>
<td>43.5x43.5</td>
<td>20.5x20.4</td>
</tr>
<tr align="center">
<td>Output Voltage</td>
<td>4.5V to 36V</td>
<td>5V to 46V</td>
<td>2.5V to 13.5V</td>
</tr>
<tr align="center">
<td>Rated Power </td>
<td>5W</td>
<td>10W</td>
<td>1.36W</td>
</tr>
</table>
</div>

## 2024/04/29 ~ 2024/05/05

**Member:** HU,SIAN-YI、LAI,MENG-CHENG、HUANG,KE-FU

**Content:**  

#### Raspberry pi 4

- When the vehicle was operating, we found that it often misidentified pink and orange as red. Initially, we tried to solve this issue by adjusting the HSV values, but even after making adjustments, we were still unable to effectively filter out these two colors. Therefore, we decided to change the color recording method and switched to using YCrCb color space. This change allowed us to more accurately identify and filter out pink and orange, improving the accuracy of color recognition.

- [References YCrCb and RGB Color Models](https://www.fuji.com.tw/posts/4934#google_vignette)

<div align="center" width=100%>
<table >
<tr align="center">
  <th>Adjusting YCrCb</th>
  </tr>
<tr align="center">
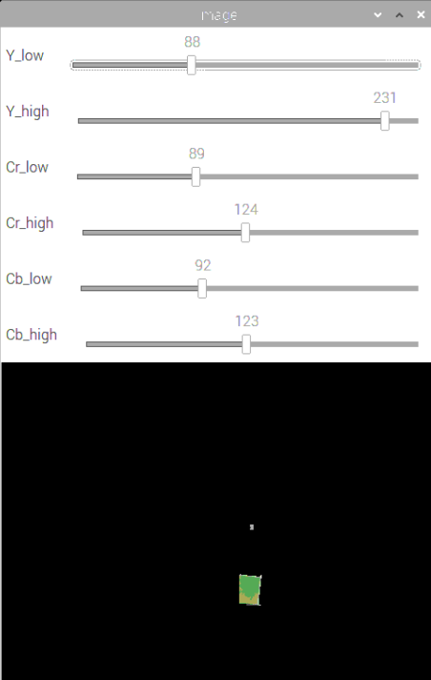
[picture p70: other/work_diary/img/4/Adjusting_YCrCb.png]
  <td>  </td>
  </td>
  </tr>
</table>
</div>

#### Jetson nano

- Since the vehicle needs to operate for long periods, we chose battery power. Considering that the motor requires a 12V voltage, we decided to use a 12V, 3A battery. We had two options: lithium-ion batteries (18650) and lithium polymer batteries (3S). However, since the 18650 battery is heavier and occupies more space, we chose the lithium polymer battery.

- The Jetson Nano supports a maximum voltage of only 5V, so we needed to use a buck converter to step down the voltage to protect the device. Initially, we planned to use the LM2596 DC-DC adjustable buck converter because it has a voltage display function. However, since its maximum supported current is only 3A, we opted for a constant voltage and constant current buck converter (ADIO-DC36V5A) that supports up to 5A. Although this module does not have a voltage display, we will install a low-voltage alarm to monitor the battery voltage and ensure it remains within a safe range.

### Comparison between 3S Li-Polymer and 18650 Li-ion batteries

<div align="center" width=100%>
<table >
<tr>
  <th> 18650 lithium batteries </th> <th>Li-Polymer 3S Battery 
  </th>
</tr>
<tr>
  <td>
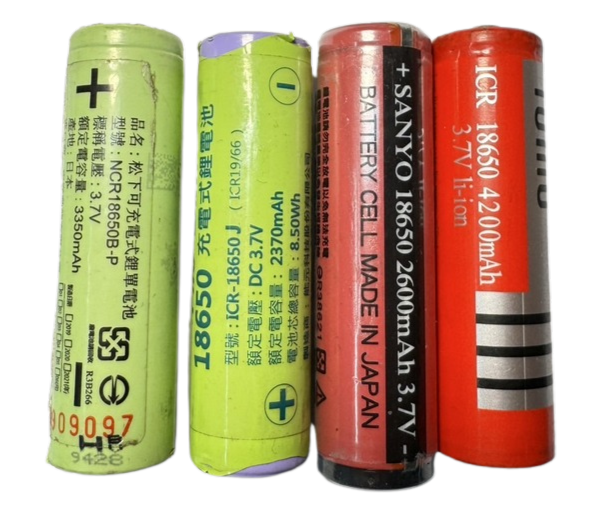
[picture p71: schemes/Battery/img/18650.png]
   </td>
  <td>
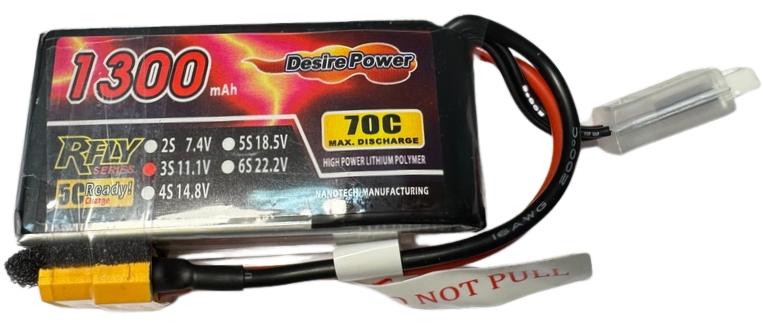
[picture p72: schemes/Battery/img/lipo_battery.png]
lipo_battery
  
  </td>
</tr>
</table>
</div>

### Step-Down power supply Module Selection

<div align="center" width=100%>
<table >
<tr align="center">
  <th> 	LM2596 DC-DC Adjustable Buck Module LM2596 DC-DC </th>
  <th>5A Constant Voltage Constant Current Buck Power Supply Module ADIO-DC36V5A</th>
</tr>
<tr align="center">
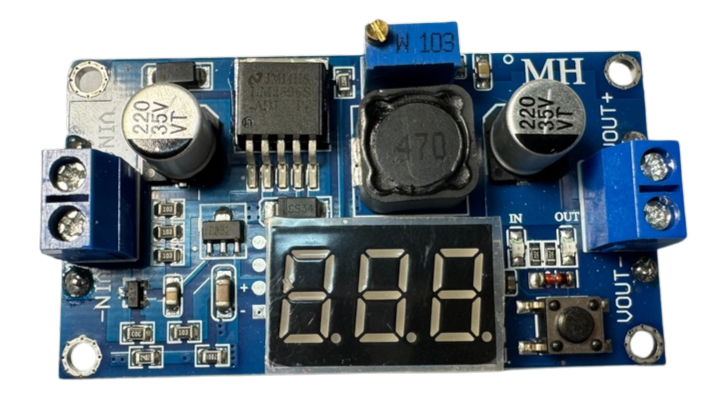
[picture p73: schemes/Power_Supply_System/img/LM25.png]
LM25
  <td>    </td>
  <td>ADIO-DC36V5A
  </td>
  </tr>
</table>
</div>

### Low Voltage Alarm

<div align="center" width=100%>
<table >
<tr align="center">
  <th> Low Voltage Alarm</th>
</tr>
<tr align="center">
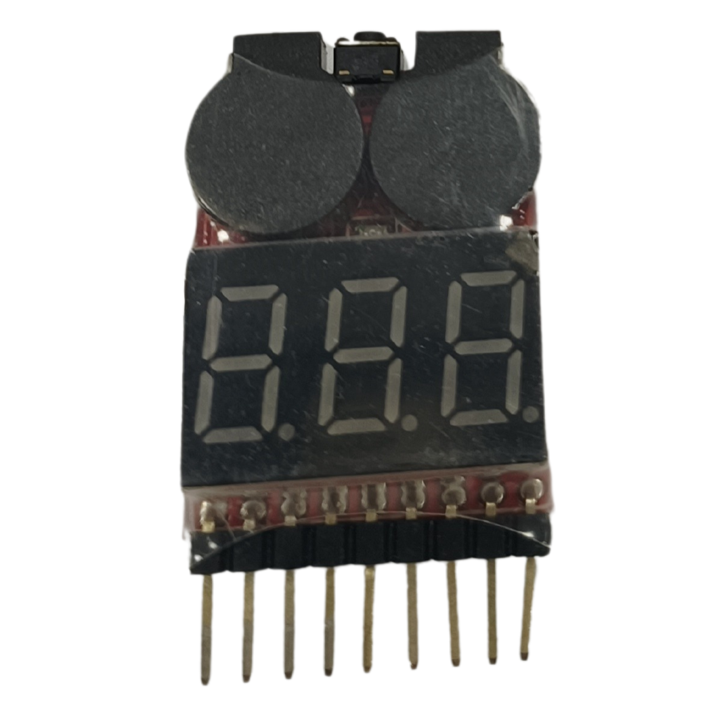
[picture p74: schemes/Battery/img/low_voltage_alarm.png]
low_voltage_alarm
  <td>    </td>

  </tr>
</table>
</div>

- We chose a lithium polymer battery (3S) as the power source for the vehicle, but an accidental charging error led to a fire and damage to the tabletop. Therefore, we must be extremely careful and cautious when using the lithium polymer battery (3S).
  <div align=center>
  <table>
  <tr>
  <th>Photo of 3S Li-Polymer (LiPo) battery burnout during charging.</th>
  </tr><tr>
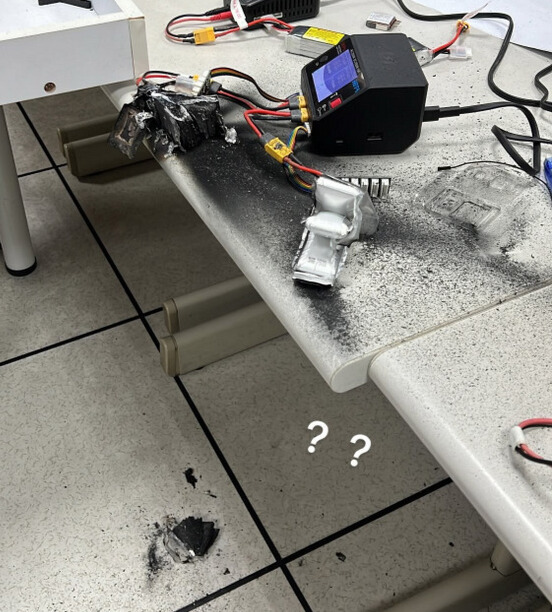
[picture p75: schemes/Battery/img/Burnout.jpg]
battery burnout during charging
  <td></td>
  </tr>
  </table>
  </div>

## 2024/05/06 ~ 2024/05/12

**Member:** HU,SIAN-YI、LAI,MENG-CHENG、HUANG,KE-FU  

**Content:**  

#### Raspberry pi 4

- The evasion issues for the Open Challenge and traffic signal blocks have been resolved. Next, we will start writing the parking action program. We plan to use LiDAR to detect walls in front of the vehicle, and when the distance is less than 50 cm, the vehicle will begin to turn. As for accurately determining the location of the parking area, it remains a challenge. We are continuing to work on solving this problem, with the goal of accurately determining whether the vehicle has entered the parking area and successfully completed the parking maneuver.

<div align="center" width=100%>
<table >
<tr align="center">
  <th>Move forward until the wall is detected</th>
  </tr>
<tr align="center">
  <td>wood  </td>
  </td>
  </tr>
</table>
</div>

#### Jetson nano

- Next, we selected the servo motor for the front wheel steering mechanism. After researching online, we found that the MG90S and SG90 are common choices. The main difference between the two is the material of the gears; the MG90S uses metal gears, while the SG90 has plastic gears. Considering that our design requires the motor to perform frequent and continuous rotations, we chose the more durable MG90S to reduce the risk of damage.

##### Front Steering Mechanism by Servo Motor

<div align="center">
<table>
<tr align="center">
<th rowspan="2">Model</th>
<th> MG90S</th>
<th >SG90</th>
</tr>
<tr align="center">
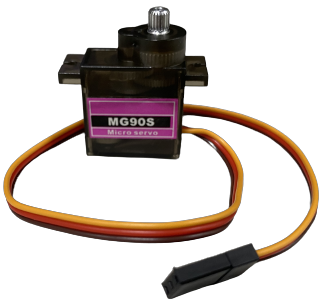
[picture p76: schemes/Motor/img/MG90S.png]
MG90S
<td></td>
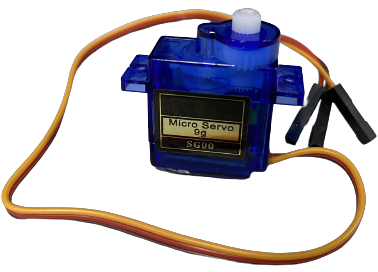
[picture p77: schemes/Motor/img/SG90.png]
SG90
<td > </td>
</tr>
<tr align="center">
<td>Rotation angle</td>
<td>90° MAX</td>
<td>360° MAX</td>
</tr>
<tr align="center">
<td>Torque</td>
<td>2.0kg/cm</td>
<td>1.4 kg/cm</td>
</tr>
<tr align="center">
<td>Speed</td>
<td>0.11s</td>
<td>0.1S</td>
</tr>
</table>
</div>

## 2024/05/13 ~ 2024/05/19

**Member:** HU,SIAN-YI、LAI,MENG-CHENG、HUANG,KE-FU  

**Content:**

#### Raspberry pi 4

- This week, we confirmed the national competition rules, determining that the parking zones are located on both sides of the starting area. Although we have a general idea of where the parking zone is, determining whether the parking zone is in the front or rear section after the vehicle enters the end zone remains a challenge. Currently, our preliminary approach is to use infrared sensors to detect the side walls of the parking zone, helping to identify the vehicle's position and determine the specific section of the parking zone.
  <div align="center" width=100%>
  <table >
  <tr align="center">
  <td colspan="2">Infrared Sensor Placement Diagram for Vehicle Position</td>
  </tr>
  <tr>
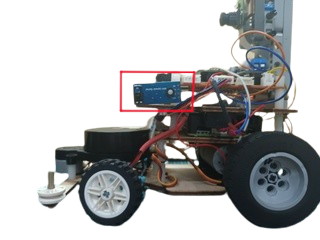
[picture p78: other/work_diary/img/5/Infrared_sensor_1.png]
    <td></td>
    <td>HC-SR04</td>
    </tr>
  </table>
  </div>

#### Jetson nano

- Through experiments, we found that the LiDAR sensor was not easy to control, so we decided to try using an ultrasonic module (HC-SR04) as a replacement for the LiDAR sensor's functionality.
- Based on this, we decided to use the ultrasonic module (HC-SR04) to complete this year's new task (parking into a parking lot). We plan to install the ultrasonic module on both sides and the rear of the vehicle to detect the parking lot's side walls, avoiding collisions with the walls. Once the parking space is detected, the vehicle will reverse and park smoothly into the space.

##### HC-SR04 ultrasonic distance sensor

<div align="center" width=100%>
<table >
<tr align="center">
<th colspan="3">HC-SR04 Ultrasonic Distance Sensor Placement Diagram on Vehicle</th>
</tr>
<tr align="center">
  <th>Left</th>
  <th>Right</th>
  <th>Right</th>
  </tr>
<tr>
  <td>HC-SR04</td>
  <td>HC-SR04</td>
  <td>HC-SR04</td>
  </tr>
</table>
</div>

## 2024/05/20 ~ 2024/05/26

**Member:** HU,SIAN-YI、LAI,MENG-CHENG、HUANG,KE-FU  

**Content:**  

#### Raspberry pi 4

- This week, we revisited the plan of using infrared sensors. We found that for the infrared sensors to detect the side walls, the vehicle needs to be very close to the walls, which would make the vehicle's width larger. However, an overly wide vehicle could cause it to collide with traffic sign blocks during the task competition. Taking this into consideration, we ultimately decided to abandon the use of infrared sensors.

#### Jetson nano

- This week, due to the change to using the MG513-P30 DC motor for the rear drive and modifications to the Ackermann steering components and bearing mounting brackets in the front steering mechanism, we used Onshape to redraw the revised part models. We then used an SLA (stereolithography) 3D printer to print these components to ensure precise dimensions and high quality.
- After printing, we needed to use a UV curing and cleaning machine to thoroughly remove any residual material, ensuring the parts were clean and ready for assembly.
- During the assembly process, we found that the photopolymer components were relatively brittle and prone to deformation. To address this issue, we performed a secondary UV curing, which effectively reduced deformation and improved the durability of these critical parts.

- ##### Onshape Model Draft

<div align="center" width=100%>
<table >
<tr align="center">
<td>Draw parts</td>
<td>Onshape Model Draft</td>
<td>onshape 3D model CAD</td>
</tr>
<tr>
  <td>Draw parts</td>
  <td>onshape</td>
  <td>onshape</td>
  </tr>
</table>
</div>
- The stereolithography (SLA) 3D printer requires regular cleaning after use. Therefore, we documented the cleaning methods learned from our predecessors and began performing our own cleaning tasks. Detailed instructions for cleaning and maintenance have been recorded in <a href="../../models/Vehicle_2D_3D/README.md#supplementary-information" target="_blank">1-1 Vehicle 2D/3D Models in CAD</a>.

  - #####  Vehicle body support components produced with Stereolithography (SLA) 3D Printer
      <div align=center>
      <table>
      <tr>
      <th>Front Assembly</th>
      <th>Steering Knuckle</th>
      <th>Steering shaft holder</th>
      <th>Cross pin</th>
      </tr><tr>
      <td>Front Assembly</td> 
      <td>Steering Knuckle</td> 
      <td>Steering-shaft-holder</td> 
      <td>Cross-pin</td>
      </tr>
      </table>
      </div> 
      <div align=center>
      <table>
      <tr>
      <th>Bearing Holder</th>
      <th colspan="2">differential housing</th>
      <th>Motor Holder</th>
      </tr><tr>
      <td>Bearing-Holder</td> 
      <td>Rear-differential-housing</td>
      <td>Rear-differential-housing</td>
      <td>Motor Holder</td>
      </tr>
      </table>
      </div> 

## 2024/05/27 ~ 2024/06/02

**Member:** HU,SIAN-YI、LAI,MENG-CHENG、HUANG,KE-FU  
**Content:**  

#### Raspberry pi 4

- Since the infrared sensor solution was not feasible, we decided to switch to using LiDAR for wall-edge detection. The vehicle will only exit the loop when the distance between the LiDAR and the wall is less than 35 cm and the wall is detected twice; otherwise, it will continue moving forward. To prevent multiple detections of the wall within a short period from causing misjudgment, we added a delay after the detection to ensure the stability of the results. This adjustment helps improve the vehicle's accuracy in recognizing walls, avoiding unnecessary stops or erroneous operations.

<div align="center" width=100%>
<table >
<tr align="center">
  <th>LiDAR wall detection code</th>
  </tr>
<tr align="center">
  <td>wood  </td>
  </td>
  </tr>
</table>
</div>

#### Jetson nano

- To enable the vehicle to correctly avoid various obstacles in complex environments, we decided to install a high-performance camera module. Considering that we are using the Jetson Nano as the controller, we selected a camera module that is highly compatible with it to ensure system stability. We ultimately chose the IMX477-160 12.3MP high-resolution camera module, which offers excellent resolution and image quality, providing clear image data. This choice not only enhances the vehicle's environmental recognition capability but also effectively improves obstacle avoidance, helping the vehicle more accurately perceive the position of obstacles during the competition.

[IMX477-160 12.3MP Camera](https://shopee.tw/%E7%8F%BE%E8%B2%A8-SONY-IMX477-%E6%94%9D%E5%BD%B1%E9%8F%A1%E9%A0%AD%E6%A8%A1%E7%B5%84-1230%E8%90%AC%E5%83%8F%E7%B4%A0-160%C2%B0%E5%BB%A3%E8%A7%92-%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)

- ### Comparison of Camera Modules
    <div align="center">
    <table>
    <tr align="center" >
    <th rowspan="2">Model</th> 
    <th >SONY IMX219</th>
    <th >SONY IMX477</th>
    </tr>
    <tr align="center">
    <td>SONY IMX219</td>
    <td>SONY IMX477</td>
    </tr>
    <tr align="center">
    <td>Sensor</td>
    <td>SONY IMX 219</td>
    <td>SONY IMX 477</td>
    </tr>
    <tr align="center">
    <td>FOV</td>
    <td>160 MAX</td>
    <td>160 MAX</td>
    </tr>
    <tr align="center">
    <td>Resolution</td>
    <td>3280 × 2464 pix</td>
    <td>4056 × 3040 pix</td>
    </tr>
    </tr>
    </table>
    </div>

    __From this, it is clear that in terms of resolution, the SONY IMX 477 is our best choice for the competition environment.__

## 2024/06/03 ~ 2024/06/09  

**Member:** HU,SIAN-YI、LAI,MENG-CHENG、HUANG,KE-FU
**Content:**

### Raspberry pi 4

- This week, during practice, the vehicle's LiDAR sensor exhibited abnormal readings. Initially, we thought the LiDAR itself was damaged, so we replaced it with a new one, but the issue persisted. We then suspected that the adapter might be the problem and replaced it, but the issue still could not be resolved. Currently, we are continuing to investigate the cause of the problem and are striving to find the best solution.

### Jetson Nano

- We installed NoMachine on the Jetson Nano to facilitate remote operations and program adjustments. Through NoMachine, we can directly access and control the Jetson Nano from any device connected to the same network, without needing to connect an HDMI monitor, keyboard, or mouse. This setup not only improved work efficiency but also made the Jetson Nano more versatile, capable of adapting to testing requirements in different locations.

- Since using NoMachine requires being on the same network, we purchased a Wi-Fi receiver and installed it in the USB port of the Jetson Nano to enable wireless connections.

- During practical testing, we found that the Wi-Fi receiver (as shown in the bottom left image) tended to hit nearby traffic signal blocks. To solve this problem, we switched to a USB 3.0 90-degree adapter to shorten the receiver’s extension angle, making it easier to avoid obstacles and prevent collisions.

<div align="center" width=100%>
<table >
<tr align="center">
  <th>NoMachine IP address selection</th>
  <th>NoMachine login screen</th>
  <th>NoMachine connected screen</th>
  </tr>
<tr align="center">
  <td>IP address</td>
  <td>login</td>
  <td>NoMachine</td>
  </tr>
</table>
</div>
<div align="center" width=100%>
<table >
<tr align="center">
  <th>USB Horizontal 180°</th>
  <th>USB Vertical 90°</th>
</tr>
<tr align="center">
  <td align="center">USB180</td>
  <td align="center">USB90</td>
</tr>
</table>
</div>

<div align="center" width=100%>
<table >
<tr align="center">
  <th >Activity photo</th>
  <th >Activity photo</th>
</tr>
<tr>
  <td align="center">site</td>
  <td align="center">work photo</td>
</tr>
</table>
</div>

## 2024/06/10 ~ 2024/06/16

**Member:** HU,SIAN-YI、LAI,MENG-CHENG、HUANG,KE-FU  

**Content:**

### Raspberry pi 4

- This week, we encountered issues with abnormal LiDAR readings. Initially, we suspected a malfunction with the LiDAR sensor itself and replaced it with a new one, but the problem persisted. We then considered the adapter might be the cause, but replacing it also did not resolve the issue. We are currently continuing to investigate the root cause to identify the best solution.

### Jetson Nano

- When writing engineering documents, we chose to use VS Code along with Git. This approach not only provides a flexible editing environment but also offers powerful version control capabilities. VS Code supports multiple programming languages and plugins, allowing us to code and write documents simultaneously, while Git enables us to track changes and easily revert to previous versions. Through Git’s branching feature, each member can work on their own branch, avoiding direct impacts on the stability of the main document. When multiple people edit the same document simultaneously, Git highlights conflicts in real time, allowing the subsequent editor to compare and merge changes, thereby improving collaboration efficiency. Additionally, the Git plugin in VS Code simplifies the overall process, enabling us to complete version management directly within the editor, which greatly enhances team collaboration efficiency and document consistency.

 <div align="center">
  
  [Engineering Documentation - WRO2024_FE-Fire-On-All-Cylinders](../../README.md) 
  
 </div>

<div align="center">
<table>
<tr align="center">
<th>To edit in VSCode, simply install Git and enter git clone.</th>
<th>Click on the "Copy Repository" option.</th>
<th>Select the repository you want to clone for editing.</th>
</tr>
<tr>
<td align="center">clone</td><td>
WEB
</td>
<td>choose</td>
</tr>
</table>
</div>

## 2024/06/17 ~ 2024/06/23

**Member:** HU,SIAN-YI、LAI,MENG-CHENG、HUANG,KE-FU  

**Content:**

### Raspberry pi 4

- Since we were unable to resolve the LiDAR issue, we began to suspect that there might be an error in the command used to call the LiDAR. However, as we were not familiar with modifying the calling program and with the competition deadline approaching, we decided to look for alternative solutions. Currently, we are considering switching to ultrasonic sensors for detection.

#### Jetson nano

- During the hardware design process, we encountered several instances where the Jetson Nano failed to power on or the Raspberry Pi Pico was unable to receive signals from the Jetson Nano due to incorrect power connections or data line misplacements. Therefore, we decided to use dual-row female headers, dual-row male headers, and Dupont wires as the connection method between the two.

<div align="center">
<table>
<tr  align="center">
<th>board</th>
<th>board</th>
</tr>
</table>
</div>

## 2024/06/24 ~ 2024/06/30  

**Member:** HU,SIAN-YI、LAI,MENG-CHENG、HUANG,KE-FU  

**Content:**

### Raspberry pi 4

- This week, we began using ultrasonic sensors to detect walls. During testing, we found that the vehicle often collided with obstacles while tracking, especially with blocks. Therefore, we decided to temporarily put the parking function development on hold and focus on perfecting the block avoidance function. Once the vehicle can reliably avoid obstacles, we will resume the development of the parking program.

### Jetson Nano

- Before avoiding blocks, we need to first complete three laps around the field. During this process, we found that the vehicle could potentially graze the wall when turning. Therefore, we decided to convert the captured camera images to grayscale and then apply binarization to identify the wall's position. Next, we used a PD control algorithm to keep the vehicle centered in the lane, ensuring it could steadily drive down the middle of the road.

- For detailed documentation on image recognition processing, please refer to <a href="../../src/Image_Recognition_Processing/README.md#adjust-floor-to-boundary-black-and-white-thresholdjetson_nano_binarizedpy" target="_blank">3-3-1 Image Recognition Processing</a>.

<div align="center">
<table>
<tr  align="center">
<th>Vehicle Collides with Side Wall</th>
<th>Highlight detection area in camera view</th>
</tr>
<tr align="center">
<td>hit wall</td>
<td>camera view</td>
</tr>
</table>
</div>

## 2024/07/01 ~ 2024/07/07

**Member:** HU,SIAN-YI、LAI,MENG-CHENG、HUANG,KE-FU  

**Content:**

### Raspberry pi 4

- As the competition date approached, we decided to temporarily set aside the research on the Jetson Nano and focus on finalizing adjustments for the Raspberry Pi 4.
During this week’s testing, we found that the vehicle often detected traffic signal blocks that were too far ahead, causing it to start the avoidance maneuver prematurely and ultimately crash into the wall. To solve this issue, we added a black mask to the top of the image frame so that the vehicle would not detect traffic signal block colors that were too distant. After applying the mask, the vehicle no longer detected overly distant block colors, successfully reducing the chances of interference.

<div align="center">
<table>
<tr align="center">
<th>Uses Black Mask to Block Out-of-Bounds Colors</th>
</tr>
<tr align="center">
<td>cover</td>
</table>
</div>

## 2024/07/08 ~ 2024/07/14

**Member:** HU,SIAN-YI、LAI,MENG-CHENG、HUANG,KE-FU  

**Content:**

### Raspberry pi 4

- After completing the block avoidance program, we began testing the machine's success rate. Initially, we chose a speed of 50%, at which the machine was mostly able to respond smoothly. However, when we increased the speed to 70%, we found that the color sensor sometimes misinterpreted the line colors on the ground due to the higher speed. To solve this issue, we adjusted the program to use LiDAR for measuring left and right directions to identify turning directions, effectively reducing the chances of incorrect turns due to color misjudgment.

#### Detects Turning Direction

```
  if get_left_dis > 100:
      reverse = False
  else:
      reverse = True
  if get_mid_dis > 55:
      servo.angle(-40)
```

## 2023/07/15 ~ 2023/07/21

**Member:** HU,SIAN-YI、LAI,MENG-CHENG、HUANG,KE-FU  

**Content:**

### Raspberry pi 4

- We are now able to complete block avoidance and the third lap around the track. The next goal is to detect the blocks and perform a U-turn. The U-turn action only needs to be executed if the last block in the second lap is red, so we first need to detect the number of laps. We will use the color sensor to record the number of times the vehicle crosses the lines and determine whether the count has exceeded the set number.

- If the count has not reached the specified number, the system will continue recording the color of the nearest traffic signal until the line-crossing count is greater than or equal to the set number, at which point it will stop recording the color.

- Once the color of the nearest traffic signal is successfully recorded, the program will check whether it is red. If the color of the signal is red, the system will set the servo motor to the right-turn angle and keep turning until the vehicle completes the designated turn. If the color of the nearest traffic signal is not red, the vehicle will continue to move forward.

<div align="center">
<table>
<tr align="center">
<th>Displays the Color of the Closest Traffic Sign and the Number of Lines</th>
<th>Adjusting Values</th>
</tr>
<tr align="center">
<td>print color</td>
<td>check</td>
</table>
</div>

## 2024/07/22 ~ 2024/07/28  

**Member:** HU,SIAN-YI、LAI,MENG-CHENG、HUANG,KE-FU  
**Content:**

- Since the field tasks have been largely completed, we have started working on the technical report. Due to our lack of familiarity with the correct standards for technical reports, we referred to the official website's documentation and found that it needs to include the following sections:

  - module: This folder should contain files related to the vehicle model, such as files for laser cutters and 3D printers. 
  - other: This folder is for data that does not fall into other categories, such as communication protocols and engineering logs. 
  - schemes: This folder is for hardware descriptions, explaining the functions of electronic components and how they are connected. 
  - src: This folder should contain all code files. 
  - t-photos: This folder should contain team photos, including one formal photo and one funny photo. 
  - v-photos: This folder should contain photos of the machine, including six different views.
  - video: This folder should contain a video of the machine in operation, which must be over 30 seconds long.

- While writing the technical documentation, we switched to using a desktop computer to view the GitHub webpage and used a laptop to edit in VS Code, as it required toggling between VS Code and the GitHub webpage.

<div align="center">
<table>
<tr align="center">
<th>Official Website's GitHub Examples</th>
<th>Adjustments for Laptop and Desktop Compatibility</th>
</tr>
<tr align="center">
<td>github_example</td>
<td>vs code</td>
</table>
</div>

## 2024/07/29 ~ 2024/08/04

**Member:** HU,SIAN-YI、LAI,MENG-CHENG、HUANG,KE-FU  

**Content:**

### Raspberry pi 4

- We have completed organizing and listing the parts inventory and uploaded it to the engineering documentation on GitHub. Additionally, we have finished the drawing work for the vehicle introduction diagram. Throughout this process, we gradually learned and became familiar with the use of GitHub syntax. Although our operation of GitHub is not yet very proficient, we have improved our skill level by consulting related information online. These advancements have provided valuable enhancements to our report.

- This week, as the task competition has been completed, we have started to continue addressing issues related to the parking area.

### Team Members' Practice Status

<div align="center">
<table>
<tr  align="center">
<td>work_photo_1_1_0727</td>
<th>work_photo_2_2_0729</th>
</tr>
</table>
</div>

## 2024/08/05 ~ 2024/08/11

**Member:** HU,SIAN-YI、LAI,MENG-CHENG、HUANG,KE-FU  

**Content:**  

### Raspberry pi 4

- This week, we completed the handling of the parking function. Although the vehicle can park smoothly, accurately projecting and parking in the lot remains a challenge.

- As the technical documentation is due next week, we began revising the content of the report and adjusting the webpage according to the official scoring criteria, while continuing to supplement the technical report and work logs.

- We recorded videos of various task solutions and uploaded them to YouTube for easy linking and referencing in the technical report.

<div align="center">
<table>
<tr align="center">
<th>The directory of engineering documentation on GitHub</th>
</tr>
<tr align="center">
<td>The directory of engineering documentation on GitHub </td>
</tr>
</table>

</div>

  **Open Challenge videos**

- [Open Challenge Full Width 60% Speed](https://www.youtube.com/watch?v=kdZ8KoKKiUw)

**Team Members' Practice Status**

<div align="center">
<table>
<tr align="center">
<th>Report writing</th>
<th>Mechanism adjustment</th>
</tr>
<tr align="center">
<td>work_daily</td>
<td>work_daily</td>
</table>
</div>

## 2024/08/12 ~ 2024/08/18

**Member:** HU,SIAN-YI、LAI,MENG-CHENG、HUANG,KE-FU  

**Content:**

### Raspberry pi 4

- This week, as our machine has successfully been adjusted to operate basic task competitions on the field smoothly, we began filming the task competition videos.

<div align="center">
<table>
<tr align="center">
<th>Modify the program and test the vehicle</th>
<tr align="center">
<td></td>
</table>
</div>

**Open Challenge videos**

- [Open Challenge videos](https://www.youtube.com/watch?v=n0Pp--26QGQ)

## 2024/08/19 ~ 2024/08/25

**Member:** HU,SIAN-YI、LAI,MENG-CHENG、HUANG,KE-FU  

**Content:**

### Raspberry pi 4

- Since the competition is scheduled to take place this week, we have already started intensive practice, trying different tasks and adjusting the program to adapt to most scenarios. The benefit of trying different tasks is that it helps us identify potential challenges the machine may face and make necessary adjustments in advance. Here is our practice method:
- We labeled the pathways as A, B, C, and D, with each pathway divided into three zones, each containing two inner and outer block placement points. Red blocks indicating turning conditions are placed sequentially, while other blocks are adjusted randomly.

We believe that this approach will help prepare our machine for various situations, ensuring that we are well-prepared for the competition.

- The competition day was August 25th. In the morning qualifiers, our vehicle successfully completed all laps in the first round and achieved full marks; however, in the second round, we had to request repairs due to abnormal radar readings. After the repairs were completed, there was only one minute left before the end of the competition, which allowed us to complete only two laps. Nevertheless, we advanced smoothly to the obstacle Challenge in the afternoon.

- In the first obstacle Challenge, the vehicle collided with a wall due to excessive evasion maneuvers, resulting in the race being halted. After adjustments, the second obstacle Challenge was completed with successful obstacle avoidance. However, the vehicle stopped without entering the finish zone, preventing us from achieving an ideal score. Fortunately, due to an opponent's mistakes, we still managed to advance.

<div align="center">
<table>
<tr align="center">
<th>Waiting for test</th>
<th>Competition photo</th>
<th>Award-winning photo</th>
</tr>
<tr align="center">
<td>work_daily</td>
<td>work_daily</td>
<td>work_daily</td>
</tr>
</table>
</div>

## 2024/08/26 ~ 2024/09/01

**Member:** HU,SIAN-YI、LAI,MENG-CHENG、HUANG,KE-FU  
**Content:**

- Since our team successfully advanced and has the opportunity to participate in the international competition, we began making improvements to the self-driving car to achieve better results. We started testing the Raspberry Pi 5 and Jetson Nano separately, planning to choose one as the new controller.

  - The Raspberry Pi 5's processor speed is 2 to 3 times that of the Raspberry Pi 4, with GPU performance being twice as strong, and the memory and I/O bandwidth also doubling that of the previous generation. It also has lower power consumption for the same tasks.
  - Compared to our original controller, the Raspberry Pi 4, the Jetson Nano has significantly higher performance and a more powerful GPU (Graphics Processing Unit), showing superior performance in camera recognition.

<div align="center">
<table>
<tr align="center">
<th>Raspberry pi 4</th>
<th>Raspberry pi 5</th>
<th>Jetson nano</th>
</tr>
<tr align="center">
<td>pi 4</td>
<td>pi 5</td>
<td>jeston nano</td>
</table>
</div>

#### Raspberry pi 5

- Currently, we are unsure which has better recognition performance, Raspberry Pi 5 or Jetson Nano. To verify this, we assembled a machine identical to the one with Raspberry Pi 4 and replaced the controller with Raspberry Pi 5, then started testing the functionality of the Raspberry Pi 5.
- When we attempted to insert the SD card used on the Raspberry Pi 4 into the Raspberry Pi 5, we found that it could not boot successfully. Therefore, we formatted the backup SD card from the Raspberry Pi 4 and burned the Raspberry Pi 5 image onto it, which finally allowed it to boot successfully.
- Next, we began the environment setup process. We first chose to install VNC so that we could operate the Raspberry Pi 5 from a computer for subsequent operations. Then, we installed the software OpenCV and ROS. OpenCV is used for processing camera images, while ROS is needed for handling radar data.

<div align="center">
<table>
<tr align="center">
<th>SD card settings</th>
<th>VNC remote connection installation</th>
<th>OpenCV installation</th>
<th>ROS installation</th>
</tr>
<tr align="center">
<td>SDcard</td>
<td>VNC</td>
<td>opencv</td>
<td>ROS</td>
</table>
</div>

#### Jetson nano

We have assembled an additional machine specifically for use with the Jetson Nano and have begun delving into its functionalities and applications. This machine will serve as our experimental platform to explore the computational capabilities and hardware integration of the Jetson Nano, laying the groundwork for future development.

- We continued restoring the self-driving car that previously used the Jetson Nano as the main controller and added the capability to recognize blue and orange lines on the field to serve as the basis for determining clockwise or counterclockwise turns.

- Therefore, we must use OpenCV to convert the captured images from RGB to HSV to correctly identify colors. The method for converting to HSV is detailed in section <a href="../../src/Image_Recognition_Processing/README.md">3-3-1 Image Recognition Processing</a>.

##### The detection status of the side walls and the blue and orange lines on the field after image processing.
<div align="center">
<table>
<tr align="center">
<th>Detect walls</th>
<th>Detect ground line (counterclockwise)</th>
</tr>

<tr align="center">
<td>wall</td>
<td>left</td>
</table>
</div>

- We determine the position of the walls by detecting the inverted white blocks on the left and right sides of the camera feed.。
- The camera detects the blue and orange y-axis to determine the vehicle's distance from the line, which helps in deciding the turning direction.。

#### Raspberry pi 4

We began addressing the issues that occurred during the national competition, using them as preparations for the future.

- In the first round of the mission race, we encountered a failure in the turning maneuver. We adjusted the turning speed and angle to ensure successful turns.

- During both mission races, the parking maneuver could not be executed as planned. Therefore, we decided not to perform parking in the mission races. Now, we are exploring alternative methods for parking.

- At the same time, we made corrections to the self-driving car with the Raspberry Pi 4 as the main controller, aiming to use it as a backup for future competitions.
  - In the first round of the task competition, we encountered a failure in making a U-turn. To address this issue, we adjusted the speed and angle of the U-turn so that the vehicle could complete it smoothly.
  - In both rounds of the task competition, the vehicle's parking actions did not proceed as expected. Therefore, we decided not to perform parking maneuvers during the task competition and plan to try other methods to achieve parking.

## 2024/09/02 ~ 2024/09/08

**Member:** HU,SIAN-YI、LAI,MENG-CHENG、HUANG,KE-FU  
**Content:**

#### Raspberry pi 5

We continued trying to transfer the functions installed on the Raspberry Pi 4 to the Raspberry Pi 5 but found that some functions could not be installed or run. For example, ROS, which is needed for running the radar, and GPIO for reading pins could not be installed and used. Only the VNC system and OpenCV for camera use were successfully installed. After researching online, we discovered that these issues might be due to version incompatibility or unsuitability, preventing us from running the main program and likely unable to be resolved in the short term. Due to these issues, we decided to temporarily pause our research on Raspberry Pi 5 and prioritize optimizing the Raspberry Pi 4 to ensure stable system operation.

<div align="center">
<table>
<tr align="center">
<th>Methods for finding solutions online.</th>
</tr>

<tr align="center">
<td>wall</td>
</table>
</div>

#### Jetson nano

- We use a camera module for recognition and a gyroscope for navigation during vehicle operation. We found that the camera module uses a 160-degree wide-angle lens, which, while expanding the field of view, also causes distortion during image capture. Therefore, we need to perform distortion correction for the wide-angle lens on the Nvidia Jetson Nano. A common correction method is using the correction function in the OpenCV library, with the detailed correction method outlined in section <a href="../../schemes/Camera/README.md#wide-angle-lens-distortion-correction"> 2-4-3 Camera Selection</a>.
- After the camera module was corrected, we combined it with the gyroscope and successfully completed the qualification test.
<div align="center">
<table>
<tr align="center">
<th>Adjust camera angle</th>
<th>Take photos</th>
</tr>

<tr align="center">
<td>wall</td>
<td>left</td>
</table>
</div>

## 2024/09/09 ~ 2024/09/15

**Member:** HU,SIAN-YI、LAI,MENG-CHENG、HUANG,KE-FU  
**Content:**

#### Raspberry pi 4

- Our Raspberry Pi 4 unexpectedly burned out for unknown reasons. To find the cause, we started by checking the power supply from the Lipo battery, using a multimeter to measure conductivity. Next, we inspected the step-down converter and used the multimeter to measure the output voltage and current of the converter, confirming that the voltage was 5V and the current was 3A. After ensuring the converter was functioning normally, we checked the circuit board wiring to see if there was a reversed polarity issue. Since we had replaced the connection cables between the circuit board and the Raspberry Pi a few days earlier, we could not be sure if the cables had caused a short circuit. After a final inspection, no abnormalities were found. Ultimately, believing that a circuit board malfunction was the most likely cause, we decided to solder a new circuit board to avoid impacting competition timing.

<div align="center">
<table>
<tr align="center">
<th>Testing the buck board</th>
<th>Testing circuit board</th>
</tr>

<tr align="center">
<td>wall</td>
<td>left</td>
</table>
</div>

#### Jetson nano

- Our self-driving car encountered some issues, and errors occurred when running the program. Upon inspecting the circuit board, we discovered that some pins on the Raspberry Pi Pico board were malfunctioning, which prevented the program from running properly. To resolve this issue, we decided to redesign the circuit diagram. Considering that the computational performance of the Jetson Nano main controller is superior to that of the Raspberry Pi Pico microcontroller, we connected the gyroscope (BNO055) sensor circuitry to the Jetson Nano controller and assigned the numerical processing tasks to the Jetson Nano. This adjustment is expected to allow for faster control of the servo motors and the front steering mechanism.

<div align="center">
<table>
<tr align="center">
<th>Remove circuit board</th>
<th>Plan route</th>
</tr>
<tr align="center">
<td>wall</td>
<td>left</td>
</table>
</div>

## 2024/09/16 ~ 2024/09/22

**Member:** HU,SIAN-YI、LAI,MENG-CHENG、HUANG,KE-FU  
**Content:**

#### Raspberry pi 4

- Over the past few days, we have completed soldering the new circuit board for the Raspberry Pi 4 controller and have also redesigned the circuit board layout to avoid excessive clutter and make the overall circuit board look more organized.

<div align="center">
<table>
<tr align="center">
<th>soldering circuit board</th>
</tr>

<tr align="center">
<td>left</td>
</table>
</div>

#### Jetson nano

- Since the self-driving car encounters misdetections during visual recognition due to the color of the vehicle's own signal wires, we decided to first use Onshape to design a cover plate model. We then used photopolymer 3D printing technology to create a cover plate that can fit precisely onto the F-shaped structure at the front of the vehicle. This cover plate effectively blocks the signal wires in front of the vehicle, thereby preventing misdetections during the camera recognition process.

<div align="center">
<table>
<tr align="center">
<th>Isometric View</th>
<th>Bottom View</th>
<th>Right View</th>
</tr>
<tr align="center">
<td>Isometric view</td>
<td>bottom view</td>
<td>right view</td>
</table>
</div>

## 2024/09/23 ~ 2024/09/29

**Member:** HU,SIAN-YI、LAI,MENG-CHENG、HUANG,KE-FU  
**Content:**

#### Raspberry pi 4

- This week, we found that using ultrasonic sensors did not allow the vehicle to stop accurately at the designated position, so we decided to revert to using radar for detection. After revising and optimizing the logic, we successfully resolved the previous issue of lidar data irregularities. Next, we will continue developing and refining the parking functionality.

#### Jetson nano

- We back up the Jetson Nano's SD card daily because there was an incident where the SD card was damaged, preventing the Jetson Nano from booting. Although the cause of the damage is still unknown, fortunately, we had previously backed up the data, so we didn't need to start from scratch and only had to restore the lost data. This backup habit effectively mitigates the risk of data loss and ensures the continuity of our development work.

<div align="center">
<table>
<tr align="center">
<th>Backup using balenaEtcher software</th>
<th>Activity photo</th>
</tr>

<tr align="center">
<td>SD</td>
<td>SD</td>
</table>
</div>

## 2024/09/30 ~ 2024/10/06

#### Raspberry pi 4

- This week, we successfully got the vehicle to drive to the area in front of the parking zone. However, when turning into the parking area, relying on the lidar sensor to detect the side wall resulted in a noticeable delay in the response to the controller, causing the vehicle to miss the intended parking spot and significantly increasing the difficulty of parking. We are currently working on finding a solution to optimize the response speed in this part, aiming to improve the vehicle's parking accuracy.

#### Jetson nano

- Since we found that the cover plate used to shield the front wires was causing the wires to be compressed, requiring additional side connections, we made modifications to the cover plate. We added a rectangular hole in the middle partition, making it easier to organize the wiring and preventing the wires from being strained, thereby enhancing the overall design's stability and convenience.

<div align="center">
<table>
<tr align="center">
<th>Cover plate without holes.</th>
<th>Cover plate for digging.</th>
</tr>
<tr align="center">
<td>Cover plate without holes</td>
<td>Cover plate for digging.</td>
</table>
</div>

## 2024/10/07 ~ 2024/10/13

**Member:** HU,SIAN-YI、LAI,MENG-CHENG、HUANG,KE-FU  
**Content:**

- After team discussions this week, we decided to abandon using the Raspberry Pi 4 as the controller due to frequent issues with color misjudgment, unstable distance measurement by the lidar sensor, and slow response in visual recognition, which hindered our ability to meet the requirements of this competition's tasks. Instead, we chose to use the Jetson Nano-controlled self-driving car as our main competition vehicle.

- This week, we completed filming the demonstration videos for GitHub and tested various combinations in the videos to see if the machine could adapt to different placements. In the qualification round, we tested four different lane width combinations; in the task competition, we tested three different placement positions for the last traffic signal block in the second lap and four different positions for the parking lot along different straight paths. The links to these videos have been recorded in sections <a href="../../video/Open_Challenge/video.md"> 5-1 Open Challenge </a> and <a href="../../video/Obstacle_Challenge/video.md">5-2 Obstacle Challenge</a>.

## 2024/10/14 ~ 2024/10/20

**Member:** HU,SIAN-YI、LAI,MENG-CHENG、HUANG,KE-FU  
**Content:**

- To address the space shortage issue with the USB version of the WiFi adapter, we added two 7mm holes in the wooden top layer of the vehicle, moving the mounting hole for the wired WiFi adapter from the middle layer to the top layer. This not only prevents the machine from becoming too bulky but also effectively utilizes the internal space of the vehicle. Additionally, since we added an HC-SR04 ultrasonic module at the rear of the middle layer for auxiliary detection during parking maneuvers, moving the WiFi adapter to the top layer frees up enough space for the HC-SR04 module's installation, further enhancing the vehicle's functional layout.

<div align="center"> 

 #### Vehicle Top Deck
<table>
<tr align="center">
<th>Before modification</th>
<th>After modification</th>
</tr>
<tr align="center">
<td>Before modification</td>
<td>After modification</td>
</table>

##### Vehicle Mid-Deck

<table>
<tr align="center">
<th>Before modification</th>
<th>After modification</th>
</tr>
<tr align="center">
<td>Before modification</td>
<td>After modification</td>
</table>
</div>

## 2024/10/21 ~ 2024/10/27

**Member:** HU,SIAN-YI、LAI,MENG-CHENG、HUANG,KE-FU  
**Content:**

- This week, we started drafting the script for the vehicle introduction. Before writing, we divided the script structure into three parts: the first part is an introduction to the vehicle's main structure, followed by an introduction to the program structure, and finally, a demonstration and explanation of the vehicle's operation video. After completing the script, we plan to finish filming this introduction video within approximately two weeks while continuing to test the vehicle's performance.

<div align="center">
<table>
<tr align="center">
<th>writing script</th>
<th>script content</th>
</tr>
<tr align="center">
<td>writing script</td>
<td>script content</td>
</table>
</div>

## 2024/10/28 ~ 2024/11/03

**Member:** HU,SIAN-YI、LAI,MENG-CHENG、HUANG,KE-FU  
**Content:**

- We discovered that during the competition, the self-driving car needs to be started by shutting down and rebooting. However, each time the Jetson Nano is turned off and restarted, a password is still required to log in, which would disrupt the competition process. Therefore, we decided to disable the login requirement to ensure smooth competition.

- The method to disable the login function on the Jetson Nano controller is as follows: go to System Settings on the Jetson Nano controller, click "User Accounts," then click "Unlock," and switch "Automatic Login" to "ON." This way, logging in will no longer be required during startup, achieving the desired effect.

<div align="center">
<table>
<tr align="center">
<th>User Adminstrator</th>
<th>Unlock</th>
<th>Automatic Login</th>
</tr>
<tr align="center">
<td>User Accounts</td>
<td></td>
<td>Automatic Login ON</td>
</table>
</div>

## 2024/11/04 ~ 2024/11/10

**Member:** HU,SIAN-YI、LAI,MENG-CHENG、HUANG,KE-FU  
**Content:**

- During the testing process, we found that the camera's position was too high. When the vehicle approached the center wall, the camera would capture images of the ground inside the center, which interfered with accurate obstacle recognition. To solve this issue, we replaced the original plastic screws with flat-headed iron screws. The flat screw heads of the iron screws provided more room for downward adjustment, allowing the circuit board to be lowered and the camera's height to be adjusted. This adjustment not only improved the camera's viewing angle but also enhanced overall stability, enabling the machine to detect obstacles more accurately and avoid capturing irrelevant ground images, thus reducing the possibility of misjudgments.

<div align="center">
<table>
<tr align="center">
<th>Plastic screws</th>
<th>Flat-headed iron screws</th>
</tr>
<tr align="center">
<td>plastic screws</td>
<td>iron screws</td>
</table>
</div>

<div align="center">
<table>
<tr align="center">
<th></th>
<th>Before modification</th>
<th>After modification</th>
</tr>
<tr align="center">
<th>Isometric view</th>
<td>Isometric view</td>
<td>Isometric view</td>
</tr>
<tr align="center">
<th>Side view</th>
<td>Side view</td>
<td>Side view</td>
</tr>
</table>
</div>

## 2024/11/11 ~ 2024/11/17

**Member:** HU,SIAN-YI、LAI,MENG-CHENG、HUANG,KE-FU  
**Content:**

#### Jetson nano

- During the vehicle testing process, we discovered that the camera would capture images of the inner side of the side wall, leading to misjudgments. To resolve this issue, we attempted to lower the vehicle body so that the camera no longer aligned with the images of the inner wall. However, this adjustment rendered the original front cover panel unsuitable. Therefore, we redesigned the front cover panel to match the modified vehicle structure.

- We shortened the front end of the cover panel and reshaped it to better fit the changes in the machine structure. This adjustment not only ensured the panel's alignment with the vehicle's exterior but also further optimized the camera's operating environment, reducing visual interference and enhancing the accuracy and stability of image detection. As shown in the figure below.

<div align="center">
<table>
<tr align="center">
<th>Competition venue map</th>
<th>Onshape Design View</th>
<th>Isometric view</th>
</tr>
<tr align="center">
<td>Onshape Design View</td>
<td>Onshape Design View</td>
<td>Isometric view</td>
</table>
</div>

- After installing the completed front cover plate onto the vehicle, we found that some signal wires were exposed, which could lead to recognition errors. To address this issue, we added partitions on both sides of the cover. This modification not only effectively hides the internal wiring but also enhances the overall appearance of the machine. Additionally, we added a wheel-like shape under the front cover plate, which not only conceals extra wiring but also improves the machine's visual appeal, making the overall design more harmonious and aesthetically pleasing.

<div align="center">
<table>
<tr align="center">
<th>Onshape Design View-Second revision</th>
<th>Isometric view</th>
</tr>
<tr align="center">
<td>Onshape Design View-Second revision<</td>
<td>Isometric view</td>
</table>
</div>

# <div align="center">HOME[Return Home](../../)</div>

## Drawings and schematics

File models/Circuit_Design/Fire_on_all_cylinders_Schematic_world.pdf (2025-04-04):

## jetson_nano schematic

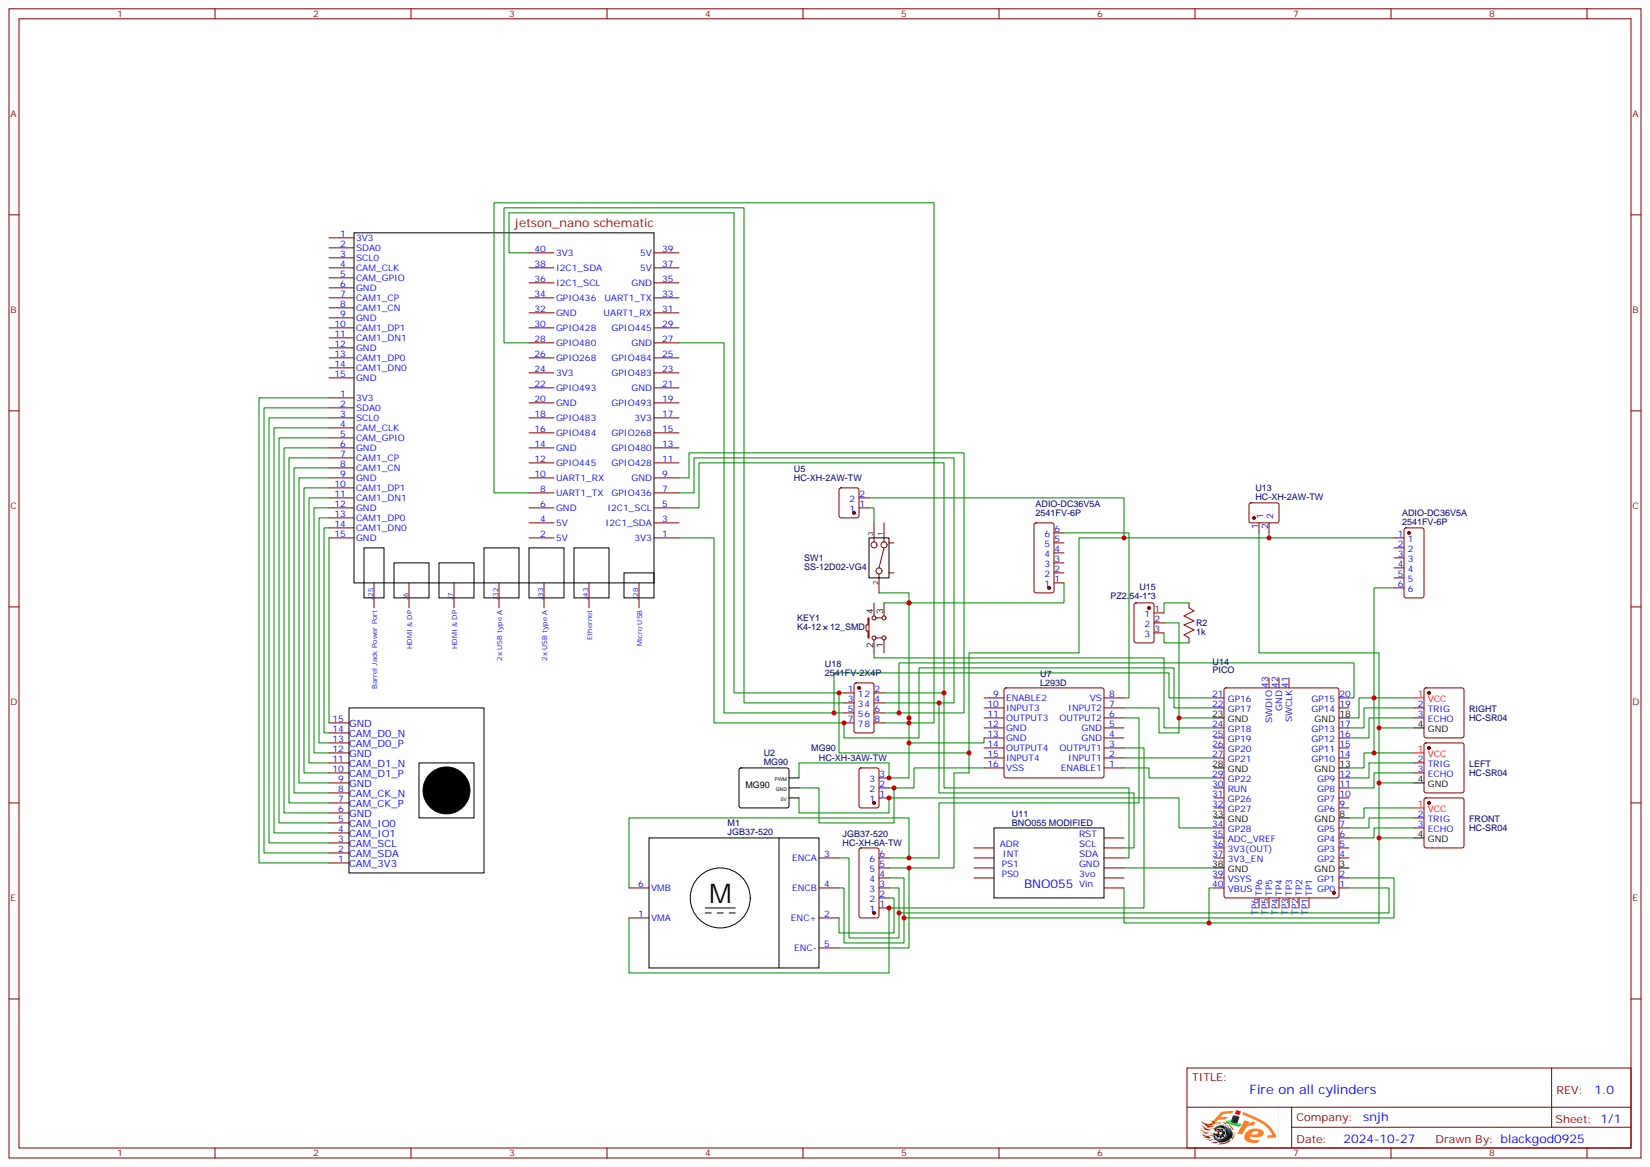
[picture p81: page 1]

Barrel Jack Power Port J25

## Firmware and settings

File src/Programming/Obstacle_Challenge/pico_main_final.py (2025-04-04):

from machine import Pin, PWM, I2C, UART, time_pulse_us
import struct
import time

# Set the pin position of ultrasound module 9
TRIG_PIN1 = 8  # Corresponds to the Trig pin of the first ultrasound module
ECHO_PIN1 = 9  # Corresponds to the Echo pin of the first ultrasound module
TRIG_PIN2 = 12  # Corresponds to the Trig pin of the second ultrasound module
ECHO_PIN2 = 13  # Corresponds to the Echo pin of the second ultrasound module

# Ultrasonic initialization pin
trig1 = Pin(TRIG_PIN1, Pin.OUT)
echo1 = Pin(ECHO_PIN1, Pin.IN)
trig2 = Pin(TRIG_PIN2, Pin.OUT)
echo2 = Pin(ECHO_PIN2, Pin.IN)

servo_pin = PWM(Pin(28), freq=50)
motor_in1 = Pin(21, Pin.OUT)
motor_in2 = Pin(20, Pin.OUT)
button_out = Pin(15, Pin.OUT)
motor_pwm = PWM(Pin(22), freq=1000)
encoder_pin_A = Pin(0, Pin.IN)
encoder_pin_B = Pin(1, Pin.IN)
button = Pin(18, Pin.IN, Pin.PULL_UP)
data_value = [0] * 3  # Initialize data list
value = [0] * 3
encoder_count = 0  # Initialize encoder count
last_state_A = encoder_pin_A.value()  # Initialize encoder status
jetson_nano_return_last = 0
# Configure UART
uart = UART(0, baudrate=115200, tx=Pin(16), rx=Pin(17))

def jetson_nano_return(number):
    global data_value
    HEADER = b"A"  # Baotou definition
    HEADER_SIZE = len(HEADER)
    DATA_SIZE = 12 # 5 integers, 4 bytes each, 20 bytes in total
    TOTAL_SIZE = HEADER_SIZE + DATA_SIZE  # Header + total length of data

    if uart.any():
        data = uart.read(TOTAL_SIZE)
        
        # Check if complete packet is received
        if len(data) == TOTAL_SIZE:
            # Find Baotou
            header_index = data.find(HEADER)
            if header_index != -1:
                # If a header is found, remove the header and extract the data
                start_index = header_index + HEADER_SIZE
                data = data[start_index:] + data[:start_index]
                data_value = struct.unpack('3i', data[:DATA_SIZE])
                return data_value[number]
            else:
                print("Error: Incorrect header received.")
        else:
            print("Error: Incomplete data received.")
    return data_value[number]
def jetson_all():
    global value
    value[0] = jetson_nano_return(0)
    value[1] = jetson_nano_return(1)
    value[2] = jetson_nano_return(2)
    print(value[0],value[1],value[2])


def encoder_interrupt(pin):
    global encoder_count, last_state_A
    state_A = encoder_pin_A.value()
    state_B = encoder_pin_B.value()
    if state_A != last_state_A:
        encoder_count += 1 if state_B != state_A else -1
    last_state_A = state_A

def run_encoder(motor_angle, speed):
    global encoder_count
    encoder_count = 0  # Reset the encoder count to zero before running
    while abs(encoder_count) < motor_angle:
        # Select PD control signal according to data_mode
        combined_control_signal = value[0]
        
        # Use control signals to adjust the servo
        set_servo_angle(combined_control_signal)
        control_motor(speed)
        
        print(f"编码器计数: {encoder_count}, combined_control_signal: {combined_control_signal}")
        jetson_all()
        time.sleep(0.01)
    control_motor(0)
    
    
def approach_until(trig, echo, threshold, operator):
    dist = measure_distance(trig, echo)
    while (dist > threshold if operator == '>' else dist < threshold):
        jetson_all()
        dist = measure_distance(trig, echo)
        control_motor(value[2])
        set_servo_angle(value[0])
        time.sleep(0.05)

def run_encoder_Auto(motor_angle, speed, string):
    global encoder_count
    encoder_count = 0  #Reset the encoder count to zero before running
    while abs(encoder_count) < motor_angle:
        # Select PD control signal according to data_mode
        combined_control_signal = string
        
        # Use control signals to adjust the servo
        set_servo_angle(combined_control_signal)
        control_motor(speed)
        
        time.sleep(0.01)
    control_motor(0)
# GPIO interrupt settings
encoder_pin_A.irq(trigger=Pin.IRQ_RISING | Pin.IRQ_FALLING, handler=encoder_interrupt)
# Define the motor control function
def control_motor(speed):
    if speed > 0:
        motor_in1.high()
        motor_in2.low()
    elif speed < 0:
        motor_in1.low()
        motor_in2.high()
    else:
        motor_in1.high()
        motor_in2.high()
    motor_pwm.duty_u16(int(abs(speed) * 65535 / 100))  # Setting the PWM duty cycle
# Set the servo angle
def set_servo_angle(angle):
    min_duty = 1000  #Corresponding to a duty cycle of 1ms
    max_duty = 2000  # Corresponding to a duty cycle of 2ms
    duty = int(min_duty + (angle-15 + 180) * (max_duty - min_duty) / 360)
    duty_u16 = int(duty * 65535 / 20000)
    servo_pin.duty_u16(duty_u16)

def measure_distance(trig, echo):
    # Send trigger pulse
    trig.value(0)
    time.sleep_us(2)
    trig.value(1)
    time.sleep_us(10)
    trig.value(0)

    # Read Echo pulse width
    duration = time_pulse_us(echo, 1)

    # Calculate distance (speed of sound is approximately 343 m/s)
    distance = (duration / 2) * 0.0343

    return distance
    

try:
    motor_in1.off()
    motor_in2.off()
    set_servo_angle(0)
    button_out.high()
    while button.value() == 1:
        time.sleep(0.1)
#         print(jetson_nano_return(0),jetson_nano_return(1),jetson_nano_return(2))
        distance2 = measure_distance(trig2, echo2)
        print(distance2)
    
    control_motor(60)

    while value[1] != 5 :
        jetson_all()
        control_motor(value[2])
        set_servo_angle(value[0])
        time.sleep(0.05)
        if value[1] == 6:
            run_encoder(3500, 60)
            control_motor(0)
            time.sleep(3)

    
    control_motor(35)
    time.sleep(0.4)
    control_motor(0)
    distance2 = measure_distance(trig2, echo2)
    distance1 = measure_distance(trig1, echo1)
    if distance1 > distance2:  # Right-side parking
        approach_until(trig2, echo2, 15, '>')
        approach_until(trig2, echo2, 20, '<')
        approach_until(trig2, echo2, 15, '>')
     # Reverse parking.
        run_encoder_Auto(300, 10, 0)
        run_encoder_Auto(1500, -45, 175)
        run_encoder_Auto(30, -10, -190)
        run_encoder_Auto(1400, -25, -190)
        run_encoder_Auto(480, 30, 180)
        run_encoder_Auto(10, 10, 0)
    # (Continue with the rest of the reverse parking sequence)
    else:  # Left-side parking
        approach_until(trig1, echo1, 15, '>')
        approach_until(trig1, echo1, 20, '<')
        approach_until(trig1, echo1, 15, '>')
    # Reverse parking.
        run_encoder_Auto(400, 10, 0)
        run_encoder_Auto(1620, -45, -190)
        run_encoder_Auto(30, -10, 180)
        run_encoder_Auto(1330, -25, 180)
        run_encoder_Auto(470, 30, -180)
        run_encoder_Auto(10, 10, 0)
    # (Continue with the rest of the reverse parking sequence)
            
    control_motor(-25)
    time.sleep(0.35)
    control_motor(0)
    button_out.low()
            
        
except KeyboardInterrupt:
    motor_in1.off()
    motor_in2.off()
    set_servo_angle(0)
    print("Program interruption")

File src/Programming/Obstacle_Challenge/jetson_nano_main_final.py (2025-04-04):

import cv2
import numpy as np
import serial as AC
import struct
import time
import Adafruit_BNO055.BNO055 as BNO055
from function import process_roi, detect_color_final, pd_control, draw_multiple_curves
import Jetson.GPIO as GPIO

# Define sensing areas
rois = [
    (350, 100, 640, 150),  # Large right sensing area
    (0, 100, 280, 150),  # Large left sensing area
    (275, 200, 355, 300),  # Final
    (305, 50, 405, 100),  # Final
    (205, 50, 305, 100)  # Final
]
led_pin = 40
GPIO.setmode(GPIO.BOARD)  # Use pin numbering
GPIO.setup(led_pin, GPIO.OUT)

# Define the color, start, and end points of multiple lines
colors = [(0, 0, 255), (0, 255, 0)]  # Red and Green
start_points = [(0, 480), (639, 470)]  # Starting point list
end_points = [(310, 35), (315, 35)]      # End point list
slope_values = [1.0, -1.0]  # Slope
curvature_factors = [0.6, 0.6]  # Curvature

target_heading = [0] * 5
left_heading = [0,-90,-180,90,0]
right_heading = [0,90,180,-90,0]
red_left_heading = [180,90,0,-90,180]
red_right_heading = [-180,-90,0,90,-180]
pink_positions = [0] * 4
color_y_positions = [0] * 4
turn_side = 0
kp_roi = 0.015  # Default data column proportional gain
kd_roi = 0.02  # Default data column differential gain
kp_heading = 4.8  # Default heading angle proportional gain
kd_heading = 5.5  # Default heading angle differential gain
kp_X = 0.5  # Default heading angle proportional gain
kd_X = 0.8  # Default heading angle differential gain
combined_control_signal = 0
count = 0
set_PWM = 70
PWM = 0
round_number = 0
turn_side = 0
turn_time = 0
turn_diside = False
pass_block = True
ROI2 = False
ROI34 = False
time1 = True
park_side = 0
stop = True
data_to_send = 0

# Load calibration data
calibration_data = np.load('calibration_data.npz')
camera_matrix = calibration_data['camera_matrix']
distortion_coefficients = calibration_data['distortion_coefficients']

# Try opening the serial port
try:
    ser = AC.Serial('/dev/ttyTHS1', 115200, timeout=1)  # Adjust the baud rate as needed
except AC.SerialException as e:
    print(f"Error: Could not open serial port: {e}")
    exit()


def main():
    global turn_side
    global target_heading
    global left_heading
    global right_heading
    global count
    global PWM
    global set_PWM
    global before_turn
    global round_number
    global turn_time
    global turn_diside
    global pass_block
    global color_y_positions
    global pink_positions
    global ROI2
    global ROI34
    global time1
    global park_side
    global stop
    global data_to_send
    window_name = "Camera Preview"
    binary_window_name = "Binary Preview"


    # Initial red and green X differences
    last_red_x_diff = 0
    last_green_x_diff = 0
    last_pink_red_x_diff = 0
    last_pink_green_x_diff = 0

    # Open the camera
    cap = cv2.VideoCapture('nvarguscamerasrc ! video/x-raw(memory:NVMM), width=640, height=480, format=(string)NV12, framerate=11/1 ! nvvidconv ! video/x-raw, format=BGRx ! videoconvert ! video/x-raw, format=BGR ! appsink drop=true sync=false', cv2.CAP_GSTREAMER)

    if not cap.isOpened():
        print("Error: Could not open video stream.")
        return
    bno = BNO055.BNO055(busnum=1)

    if not bno.begin():
        raise RuntimeError('Failed to initialize BNO055!')
    combined_control_signal = 0
    start_time = 0
    current_time = 0
    elapsed_time = 0
    time_count = 0
    turn_time = 0
    GPIO.output(led_pin, GPIO.HIGH)
    while True:
        ret, frame = cap.read()
        if not ret:
            break
        # Read BNO055 sensor data
        heading, roll, pitch = bno.read_euler()
        accel_x, accel_y, accel_z = bno.read_linear_acceleration()
        if heading > 180:
            heading -= 360
        # Distortion correction of images using calibration parameters
        h, w = frame.shape[:2]
        new_camera_matrix, roi = cv2.getOptimalNewCameraMatrix(camera_matrix, distortion_coefficients, (w, h), 0.14, (w, h))
        undistorted_frame = cv2.undistort(frame, camera_matrix, distortion_coefficients, None, new_camera_matrix)

        # Create a binarized copy
        gray = cv2.cvtColor(undistorted_frame, cv2.COLOR_BGR2GRAY)
        _, binary_frame = cv2.threshold(gray, 105, 255, cv2.THRESH_BINARY)
        binary_frame = cv2.cvtColor(binary_frame, cv2.COLOR_GRAY2BGR)

        # Processing each sensing area
        roi_values = []
        for x1, y1, x2, y2 in rois:
            processed_roi, black_pixels = process_roi(undistorted_frame, x1, y1, x2, y2)
            roi_values.append(black_pixels)
            binary_frame[y1:y2, x1:x2] = processed_roi

       
        # Color detection, and pass red_curve_points into it to get the X difference between red and green
        color_y_positions, pink_positions, red_x_diff, green_x_diff, pink_red_x_diff, pink_green_x_diff = detect_color_final(undistorted_frame, last_red_x_diff, last_green_x_diff, last_pink_red_x_diff, last_pink_green_x_diff, start_points, end_points, slope_values, curvature_factors, colors)

        # Save the current red and green X differences for use in the next frame
        last_red_x_diff = red_x_diff
        last_green_x_diff = green_x_diff
        last_pink_red_x_diff = pink_red_x_diff
        last_pink_green_x_diff = pink_green_x_diff
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
